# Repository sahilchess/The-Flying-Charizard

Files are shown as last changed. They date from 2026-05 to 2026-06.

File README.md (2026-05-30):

# The Flying Charizard 

A Simple STM32-based flight controller PCB with Charizard-themed artwork etched into the board layers.

## Overview

The Flying Charizard is a fully custom PCB designed around the **STM32F722RETx** microcontroller for flight control applications.  
It combines practical avionics hardware with Pokémon-inspired PCB art across copper and silkscreen layers.

## Features

- STM32 microcontroller (**STM32F722RETx**)
- USB-C power and communication
- Battery charge management (**RA9357RNER**)
- Buck-boost converter (**TPS63070RNNR**) for stable power delivery
- Barometric pressure sensor (**BMP390**)
- Accelerometer / gyroscope (**KN-45696**) for IMU
- Dual crystal oscillators
- SD card interface
- 2x servo headers
- Reset and boot buttons
- LiPo battery connector (BAT+)
- Custom Charizard copper art across F.Cu and B.Cu layers

## Schematic Sections

| Block | Component |
|---|---|
| MCU | STM32F722RETx |
| USB-C | TYPE-C 16PIN 2MD |
| Pressure Sensor | BMP390 |
| IMU | KN-45696 (Accel/Gyro) |
| Battery Charger | RA9357RNER |
| Buck-Boost | TPS63070RNNR |
| Power Switch | LM951130 |
| SD Card | OLA-Z2869250 |

## PCB

Designed in **KiCad** as a **2-layer board** with Charizard artwork embedded in copper pours and silkscreen.

The artwork includes:
- Charizard
- Dragonite
- Charmander
- Mega Charizard X

## Gallery

### Schematic
Flying Charizard Schematic

### PCB / Artwork
Flying Charizard Image 2
Flying Charizard Image 3
Flying Charizard Image 4

## Author

[@Sahild](https://github.com/Sahild)

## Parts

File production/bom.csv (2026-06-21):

Designator | Footprint | Quantity | Value | LCSC Part #
C1, C28, C29, C30 | 0402 | 4 | 1uF
C10, C13, C17, C18 | 0603 | 4 | 22uF
C12, C2, C3, C31, C5, C6, C7, C8, C9 | 0402 | 9 | 10uF
C14, C15, C19, C20, C21, C22, C23, C25, C26, C37 | 0402 | 10 | 100nF
C16, C32 | 0402 | 2 | 2.2uF
C33, C34 | 0402 | 2 | 20pF
C35, C36 | 0402 | 2 | 6.8pF
C4 | 0402 | 1 | 47nF
CARD1 | TF-SMD_TF-02 | 1 | TF-01A_C2889258 | C2889258
D1 | 0603 | 1 | LED
J1 | TerminalBlock_Phoenix_MKDS-1,5-2_1x02_P5.00mm_Horizontal | 1 | Screw_Terminal_01x02
J2, J3 | PinHeader_1x03_P2.54mm_Vertical | 2 | Conn_01x03
L1 | L2520 | 1 | 1uH | C435392
L2 | IND-SMD_L4.0-W4.0-A | 1 | 1.5uH | C3033018
L3 | IND-SMD_L3.0-W3.0 | 1 | 5.6uH | C18236327
L4 | L0603 | 1 | FCM1608KF-601T03 | C141723
R1, R2 | 0402 | 2 | 5.1K
R10, R11, R12, R13, R16, R17, R18, R19, R20, R21, R22, R6, R8, R9 | 0402 | 14 | 10K
R14 | 0603 | 1 | 100K
R15 | 0402 | 1 | 22.1K
R3 | 0402 | 1 | 383
R4 | 0402 | 1 | 5.23K
R5 | 0402 | 1 | 30.1K
SW1, SW2 | SW-SMD_L3.9-W3.0-P4.45 | 2 | TS-1088-AR02016 | C720477
U1 | VFQFPN-24_L4.0-W4.0-P0.50-BL-EP2.8 | 1 | BQ25883RGER | C544362
U2 | VQFN-15_L3.0-W2.5-P0.50-BL | 1 | TPS63070RNMR | C109322
U3 | SOT-23-6_L2.9-W1.6-P0.95-LS2.8-BR | 1 | LMR51430 | C5210749
U4 | LGA-14_L3.0-W2.5-P0.50-TL | 1 | ICM-45686 | C22459454
U5 | LQFP-64_L10.0-W10.0-P0.50-LS12.0-BL | 1 | STM32F722RETx | C118207
U6 | LGA-10_L2.0-W2.0-P0.50-TL_BMP580 | 1 | BMP580 | C22391138
USB1 | USB-C-SMD_TYPE-C-16PIN-2MD-073 | 1 | TYPE-C 16PIN 2MD | C2765186
X1 | CRYSTAL-SMD_4P-L3.2-W2.5-BL | 1 | X322525MOB4SI | C9006
X2 | FC-135R_L3.2-W1.5 | 1 | Q13FC1350000400 | C32346

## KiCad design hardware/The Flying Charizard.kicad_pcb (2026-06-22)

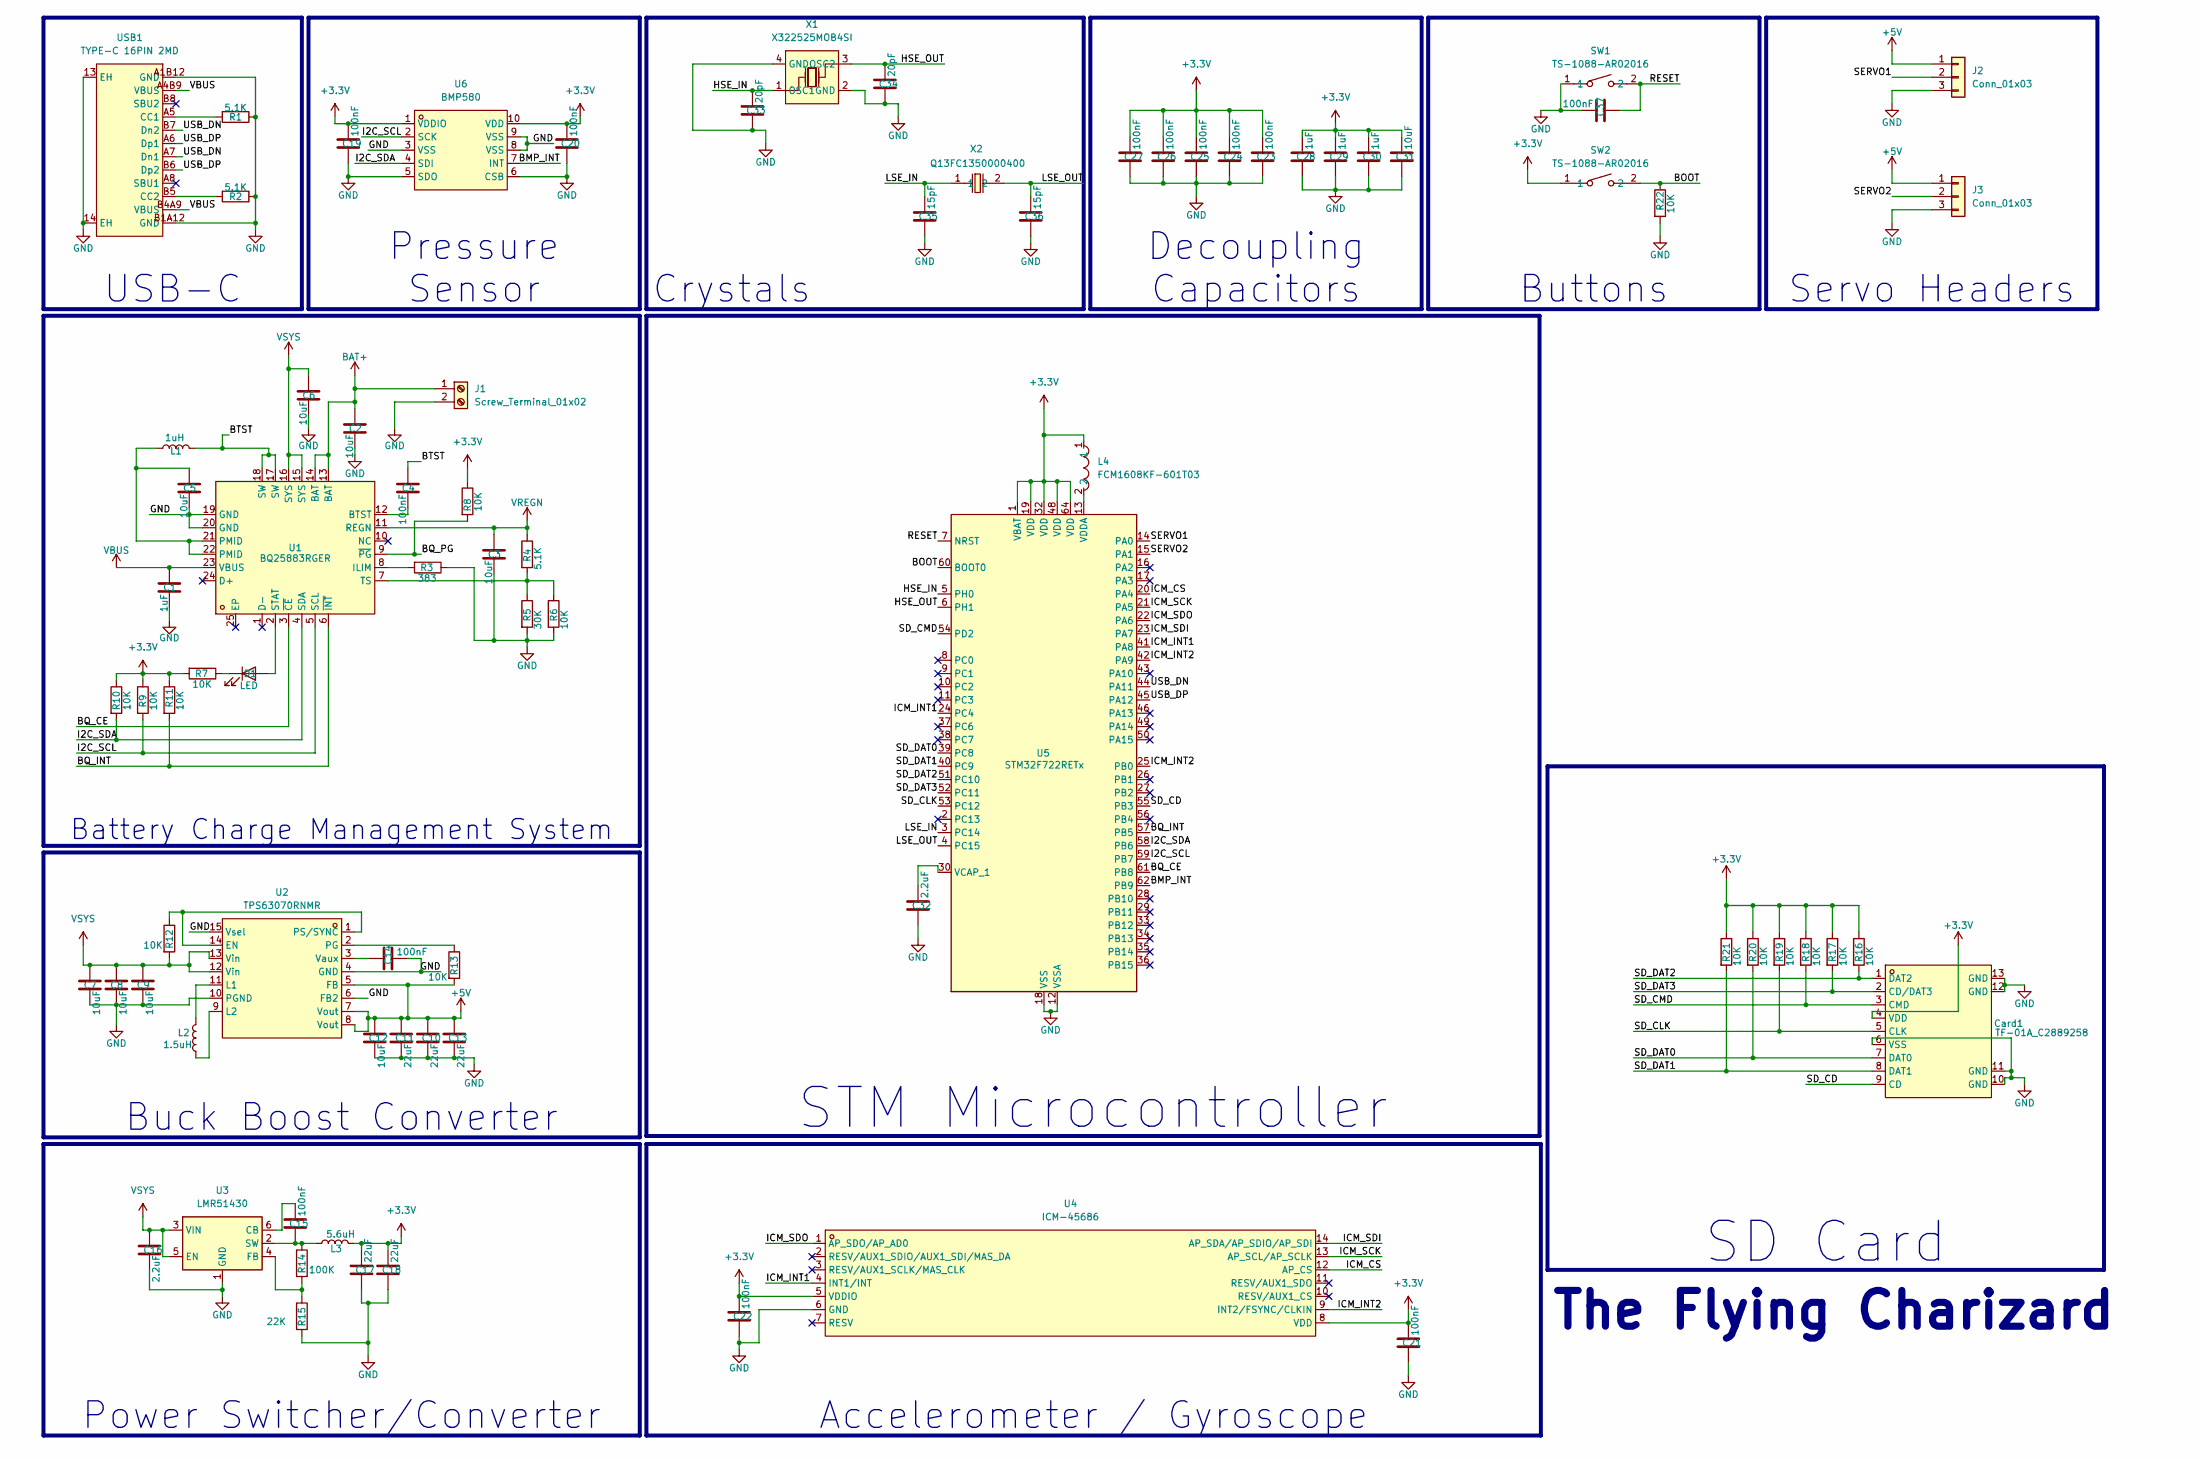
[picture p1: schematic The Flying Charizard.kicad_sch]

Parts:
C1, C28, C29, C30: 1uF; R_0402_1005Metric
C2, C3, C5, C6, C7, C8, C9, C12, C31: 10uF; R_0402_1005Metric
C4, C14, C15, C19, C20, C21, C22, C23, C24, C25, C26, C27, C37: 100nF; R_0402_1005Metric
C10, C11, C13, C17, C18: 22uF; R_0603_1608Metric
C16, C32: 2.2uF; R_0402_1005Metric
C33, C34: 20pF; R_0402_1005Metric
C35, C36: 15pF; R_0402_1005Metric
Card1: TF-01A_C2889258; TF-SMD_TF-02; MPN TF-01A; LCSC Part C2889258
D1: LED; LED_0603_1608Metric
J1: Screw_Terminal_01x02; TerminalBlock_Phoenix_MKDS-1,5-2_1x02_P5.00mm_Horizontal
J2, J3: Conn_01x03; PinHeader_1x03_P2.54mm_Vertical
L1: 1uH; L2520
L2: 1.5uH; IND-SMD_L4.0-W4.0-A
L3: 5.6uH; IND-SMD_L3.0-W3.0
L4: FCM1608KF-601T03; L0603; MPN FCM1608KF-601T03; LCSC Part C141723
R1, R2, R4: 5.1K; R_0402_1005Metric
R3: 383; R_0402_1005Metric
R5: 30K; R_0402_1005Metric
R6, R7, R8, R9, R10, R11, R12, R13, R16, R17, R18, R19, R20, R21, R22: 10K; R_0402_1005Metric
R14: 100K; R_0603_1608Metric
R15: 22K; R_0402_1005Metric
SW1, SW2: TS-1088-AR02016; SW-SMD_L3.9-W3.0-P4.45; MPN TS-1088-AR02016; LCSC Part C720477
U1: BQ25883RGER; VFQFPN-24_L4.0-W4.0-P0.50-BL-EP2.8; MPN BQ25883RGER; LCSC Part C544362
U2: TPS63070RNMR; VQFN-15_L3.0-W2.5-P0.50-BL; MPN TPS63070RNMR; LCSC Part C109322
U3: LMR51430; SOT-23-6_L2.9-W1.6-P0.95-LS2.8-BR
U4: ICM-45686; LGA-14_L3.0-W2.5-P0.50-TL; MPN ICM-45686; LCSC Part C22459454
U5: STM32F722RETx; LQFP-64_L10.0-W10.0-P0.50-LS12.0-BL
U6: BMP580; LGA-10_L2.0-W2.0-P0.50-TL_BMP580; MPN BMP580; LCSC Part C22391138
USB1: TYPE-C 16PIN 2MD; USB-C-SMD_TYPE-C-16PIN-2MD-073; MPN TYPE-C 16PIN 2MD(073); LCSC Part C2765186
X1: X322525MOB4SI; CRYSTAL-SMD_4P-L3.2-W2.5-BL; MPN X322525MOB4SI; LCSC Part C9006
X2: Q13FC1350000400; FC-135R_L3.2-W1.5; MPN Q13FC13500004; LCSC Part C32346

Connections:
+3.3V: C17.1, C18.1, C19.1, C20.1, C21.1, C22.1, C23.1, C24.1, C25.1, C26.1, C27.1, C28.1, C29.1, C30.1, C31.1, Card1.4 (VDD), L3.2, L4.1, R7.2, R8.1, R9.1, R10.1, R11.1, R16.1, R17.1, R18.1, R19.1, R20.1, R21.1, SW2.1, U4.5 (VDDIO), U4.8 (VDD), U5.1 (VBAT), U5.19 (VDD), U5.32 (VDD), U5.48 (VDD), U5.64 (VDD), U6.1 (VDDIO), U6.10 (VDD)
+5V: C10.1, C11.1, C12.1, C13.1, J2.1, J3.1, R13.2, U2.5 (FB), U2.7 (Vout), U2.8 (Vout)
/BMP_INT: U5.62 (PB9), U6.7 (INT)
/BOOT: R22.1, SW2.2, U5.60 (BOOT0)
/BQ_CE: U1.3 (~CE), U5.61 (PB8)
/BQ_INT: R11.2, U1.6 (~INT), U5.57 (PB5)
/BQ_PG: R8.2, U1.9 (~PG)
/BTST: C4.1, L1.2, U1.17 (SW), U1.18 (SW)
/HSE_IN: C33.1, U5.5 (PH0), X1.1 (OSC1)
/HSE_OUT: C34.1, U5.6 (PH1), X1.3 (OSC2)
/I2C_SCL: R9.2, U1.5 (SCL), U5.59 (PB7), U6.2 (SCK)
/I2C_SDA: R10.2, U1.4 (SDA), U5.58 (PB6), U6.4 (SDI)
/ICM_CS: U4.12 (AP_CS), U5.20 (PA4)
/ICM_INT1: U4.4 (INT1/INT), U5.24 (PC4), U5.41 (PA8)
/ICM_INT2: U4.9 (INT2/FSYNC/CLKIN), U5.25 (PB0), U5.42 (PA9)
/ICM_SCK: U4.13 (AP_SCL/AP_SCLK), U5.21 (PA5)
/ICM_SDI: U4.14 (AP_SDA/AP_SDIO/AP_SDI), U5.23 (PA7)
/ICM_SDO: U4.1 (AP_SDO/AP_AD0), U5.22 (PA6)
/LSE_IN: C35.1, U5.3 (PC14), X2.1
/LSE_OUT: C36.1, U5.4 (PC15), X2.2
/RESET: C37.2, SW1.2, U5.7 (NRST)
/SD_CD: Card1.9 (CD), U5.55 (PB3)
/SD_CLK: Card1.5 (CLK), R19.2, U5.53 (PC12)
/SD_CMD: Card1.3 (CMD), R18.2, U5.54 (PD2)
/SD_DAT0: Card1.7 (DAT0), R20.2, U5.39 (PC8)
/SD_DAT1: Card1.8 (DAT1), R21.2, U5.40 (PC9)
/SD_DAT2: Card1.1 (DAT2), R16.2, U5.51 (PC10)
/SD_DAT3: Card1.2 (CD/DAT3), R17.2, U5.52 (PC11)
/SERVO1: J2.2, U5.14 (PA0)
/SERVO2: J3.2, U5.15 (PA1)
/USB_DN: U5.44 (PA11), USB1.A7 (Dn1), USB1.B7 (Dn2)
/USB_DP: U5.45 (PA12), USB1.A6 (Dp1), USB1.B6 (Dp2)
BAT+: C2.1, J1.1, U1.13 (BAT), U1.14 (BAT)
GND: C1.2, C2.2, C3.2, C5.2, C6.2, C7.2, C8.2, C9.2, C10.2, C11.2, C12.2, C13.2, C14.2, C16.2, C17.2, C18.2, C19.2, C20.2, C21.2, C22.2, C23.2, C24.2, C25.2, C26.2, C27.2, C28.2, C29.2, C30.2, C31.2, C32.2, C33.2, C34.2, C35.2, C36.2, C37.1, Card1.6 (VSS), Card1.10 (GND), Card1.11 (GND), Card1.12 (GND), Card1.13 (GND), J1.2, J2.3, J3.3, R1.1, R2.1, R3.1, R5.2, R6.2, R15.2, R22.2, SW1.1, U1.19 (GND), U1.20 (GND), U2.4 (GND), U2.6 (FB2), U2.10 (PGND), U2.15 (Vsel), U3.1 (GND), U4.6 (GND), U5.12 (VSSA), U5.18 (VSS), U5.31 (VSS), U5.47 (VSS), U5.63 (VSS), U6.3 (VSS), U6.5 (SDO), U6.6 (CSB), U6.8 (VSS), U6.9 (VSS), USB1.13 (EH), USB1.14 (EH), USB1.A1B12 (GND), USB1.B1A12 (GND), X1.2 (GND), X1.4 (GND)
unnamed: C5.1, L1.1, U1.21 (PMID), U1.22 (PMID)
unnamed: D1.2 (A), U1.2 (STAT)
unnamed: D1.1 (K), R7.1
unnamed: C4.2, U1.12 (BTST)
unnamed: R3.2, U1.8 (ILIM)
unnamed: R4.2, R5.1, R6.1, U1.7 (TS)
unnamed: R12.1, U2.1 (PS/SYNC), U2.14 (EN)
unnamed: L2.2, U2.11 (L1)
unnamed: L2.1, U2.9 (L2)
unnamed: R13.1, U2.2 (PG)
unnamed: C14.1, U2.3 (Vaux)
unnamed: C15.1, U3.6 (CB)
unnamed: R14.2, R15.1, U3.4 (FB)
unnamed: C15.2, L3.1, R14.1, U3.2 (SW)
unnamed: C32.1, U5.30 (VCAP_1)
unnamed: L4.2, U5.13 (VDDA)
unnamed: R1.2, USB1.A5 (CC1)
unnamed: R2.2, USB1.B5 (CC2)
VBUS: C1.1, U1.23 (VBUS), USB1.A4B9 (VBUS), USB1.B4A9 (VBUS)
VREGN: C3.1, R4.1, U1.11 (REGN)
VSYS: C6.1, C7.1, C8.1, C9.1, C16.1, R12.2, U1.15 (SYS), U1.16 (SYS), U2.12 (Vin), U2.13 (Vin), U3.3 (VIN), U3.5 (EN)

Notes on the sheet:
The Flying Charizard
USB-C
Servo Headers
STM Microcontroller
Crystals
Power Switcher/Converter
Buttons
Decoupling Capacitors
Battery Charge Management System
Pressure Sensor
Accelerometer / Gyroscope
Buck Boost Converter
SD Card

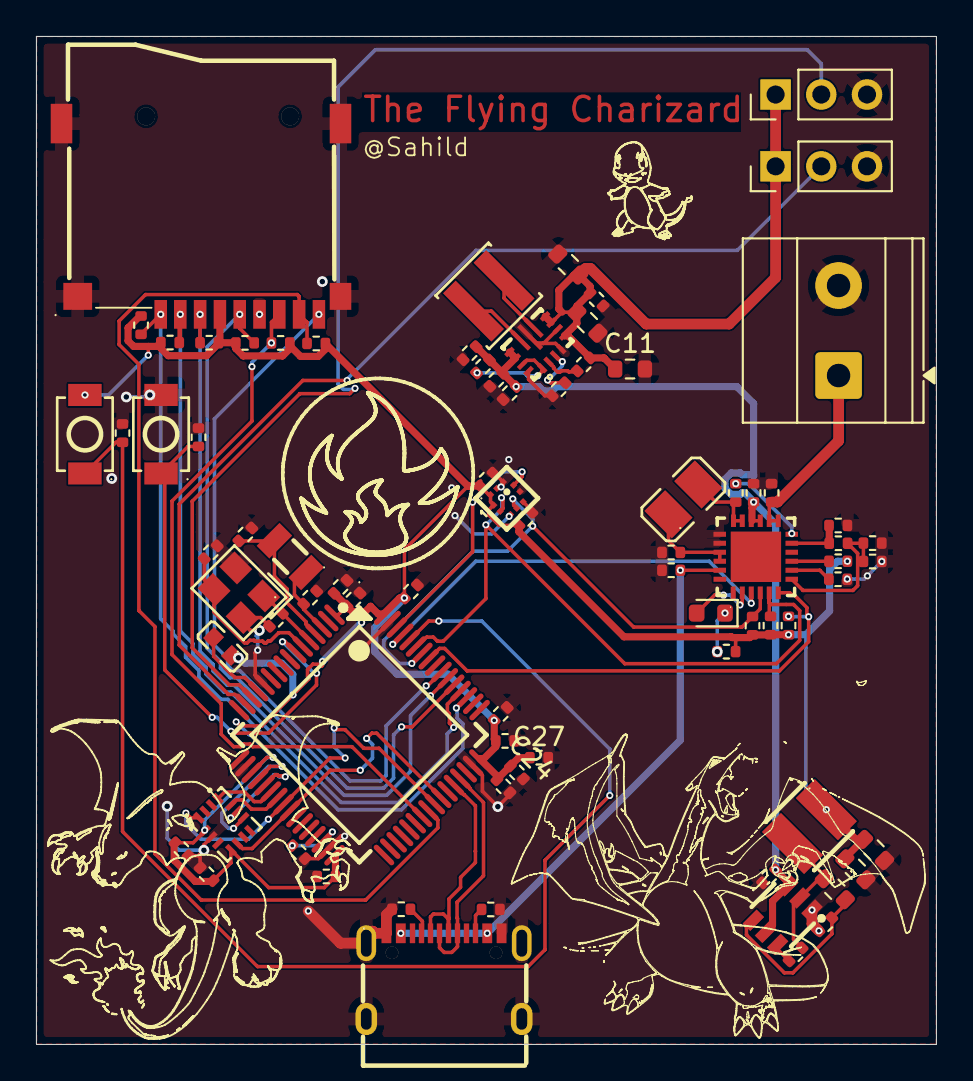
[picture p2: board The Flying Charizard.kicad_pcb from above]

Board: 2 copper layers, 50.0 x 56.0 mm, 79 parts (0 on the bottom side), 55 nets.

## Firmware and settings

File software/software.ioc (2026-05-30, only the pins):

Mcu.UserName=STM32F722RETx
PA0-WKUP.Signal=S_TIM2_CH1_ETR
PA1.Signal=S_TIM2_CH2
PA11.Signal=USB_OTG_FS_DM
PA12.Signal=USB_OTG_FS_DP
PA4.Signal=SPI1_NSS
PA5.Signal=SPI1_SCK
PA6.Signal=SPI1_MISO
PA7.Signal=SPI1_MOSI
PB0.GPIO_Label=ICM_INT2
PB0.Signal=GPXTI0
PB3.GPIO_Label=SD_CS
PB3.Signal=GPIO_Input
PB5.GPIO_Label=BQ_INT
PB5.Signal=GPXTI5
PB6.Signal=I2C1_SCL
PB7.Signal=I2C1_SDA
PB8.GPIO_Label=BQ_CE
PB8.Signal=GPIO_Output
PB9.GPIO_Label=BMP_INT
PB9.Signal=GPXTI9
PC10.Signal=SDMMC1_D2
PC11.Signal=SDMMC1_D3
PC12.Signal=SDMMC1_CK
PC14-OSC32_IN.Signal=RCC_OSC32_IN
PC15-OSC32_OUT.Signal=RCC_OSC32_OUT
PC8.Signal=SDMMC1_D0
PC9.Signal=SDMMC1_D1
PD2.Signal=SDMMC1_CMD
PH0-OSC_IN.Signal=RCC_OSC_IN
PH1-OSC_OUT.Signal=RCC_OSC_OUT

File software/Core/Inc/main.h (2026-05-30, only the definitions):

#define ICM_INT2_Pin GPIO_PIN_0
#define ICM_INT2_GPIO_Port GPIOB
#define SD_CS_Pin GPIO_PIN_3
#define SD_CS_GPIO_Port GPIOB
#define BQ_INT_Pin GPIO_PIN_5
#define BQ_INT_GPIO_Port GPIOB
#define BQ_CE_Pin GPIO_PIN_8
#define BQ_CE_GPIO_Port GPIOB
#define BMP_INT_Pin GPIO_PIN_9
#define BMP_INT_GPIO_Port GPIOB

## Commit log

2026-05-30 Add README for Flying Charizard flight controller
    Added detailed description of the Flying Charizard flight controller PCB, including features, schematic sections, PCB design, and gallery.
2026-06-21 production stuff
    [bom.csv, designators.csv, positions.csv]

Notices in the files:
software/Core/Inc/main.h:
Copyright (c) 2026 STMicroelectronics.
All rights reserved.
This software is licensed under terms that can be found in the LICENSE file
